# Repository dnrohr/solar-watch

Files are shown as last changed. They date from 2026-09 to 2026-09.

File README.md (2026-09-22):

# Solar Watch

The repository contains the digitally validated P0 solar reference, the P1
fixed-latitude cam bench, and the Rev-A CNC-ready P2 fixed-latitude display for
42.1 degrees north. P2 is ready for quotation and physical coupon/module tests;
its fabrication-dependent accuracy is not yet claimed.

## P2 release package

- `output/pdf/solar_watch_p2_design_dossier_revA.pdf` — design basis,
  validation evidence, interfaces, verification matrix, and risks;
- `output/pdf/solar_watch_p2_custom_part_drawings_revA.pdf` — 28 controlled
  custom-part sheets;
- `output/pdf/solar_watch_p2_procurement_test_revA.pdf` — BOM, RFQ, assembly,
  calibration, and acceptance procedure;
- `cnc/p2/` — STEP, DXF, STL preview, cam profile CSV, assembly STEP, manifest,
  and SHA-256 list;
- `src/solar_watch/p2.py` and `src/solar_watch/p2_cad.py` — kinematic and CAD
  sources.

Run `scripts/bootstrap.ps1`, then `scripts/regenerate.ps1` and
`scripts/verify.ps1`. PDF generation additionally uses the free ReportLab
runtime documented in `docs/software-tooling.md`.

Solar Watch is a large-format mechanical astronomical display. Its
three solar indications show:

- sunrise time;
- sunset time; and
- sunrise and sunset azimuth on one 360-degree dial.

The target demonstrator occupies no more than a 36 by 24 inch frontal area and
accepts latitude and date as astronomical inputs. A conventional clock movement
may later provide local time independently.

The P0 numerical reference, P1 cam package, and P2 CNC design are complete in
software for 42.1 degrees north. Decision 0006 records the user's choice to
bypass P1 fabrication. The next action is to quote and machine the P2 coupons,
then release production parts only after those coupons pass.

## Start here

- [Project brief](docs/project-brief.md)
- [Requirements](docs/requirements.md)
- [Conventions](docs/conventions.md)
- [Provisional architecture](docs/architecture.md)
- [Risk register](docs/risk-register.md)
- [Software and tooling](docs/software-tooling.md)
- [Open decisions](docs/open-decisions.md)
- [P0 numerical validation](docs/p0-validation.md)
- [P1 cam package](docs/p1-cam-package.md)
- [P1 bill of materials](docs/bom.md)
- [Print and test procedure](docs/print-test-procedure.md)
- [P2 design basis](docs/p2-design-basis.md)
- [P2 interface control](docs/p2-interface-control.md)
- [P2 mechanical analysis](docs/p2-mechanical-analysis.md)
- [P2 bill of materials](docs/p2-bom.md)
- [P2 RFQ](docs/p2-rfq.md)
- [P2 vendor shortlist and budget](docs/p2-vendor-budget.md)
- [P2 manufacture and test](docs/p2-manufacturing-test.md)

## Reproduce and verify P0/P1/P2

The toolchain is free and project-local. From PowerShell with Python 3.12:

```powershell
.\scripts\bootstrap.ps1
.\scripts\verify.ps1
```

Generated reference data lives in `data/`, diagnostic plots in
`artifacts/plots/`, print-ready P1 files in `printables/p1/`, and CNC P2 files in
`cnc/p2/`.
Normal verification is offline; refreshing the independent JPL DE421 fixture is
an explicit separate command documented in the P0 report.

Documents marked **Provisional** contain assumptions that may change after the
first design review.

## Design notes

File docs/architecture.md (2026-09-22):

# Provisional System Architecture

Status: P2 Rev A
Date: 2026-09-21

## Functional decomposition

```text
Calendar input ─┬─> solar-geometry function ─> sunrise azimuth ─> sunrise hand
                │                                      └───────> mirrored sunset hand
Latitude input ─┘

Calendar input ─┬─> daylight function ─> daylight-duration displacement ─┐
Latitude input ─┘                                                         │
                                                                          v
Manual sunrise-time input ─────────────────────────────────────────> time summer
                                                                          │
                                                                          v
                                                                  sunset-time hand
```

The local-time clock, if installed, is an independent module.

## Computational degrees of freedom

The ideal-horizon mechanism needs to generate only two independent astronomical
outputs:

1. sunrise azimuth; and
2. daylight duration.

Sunset azimuth is obtained by reflection around the north-south meridian.
Sunset time is obtained by adding daylight duration to an established sunrise
time. This reduction is central to keeping the printed mechanism achievable.

## Proposed final modules

### A. Input module

- Manually positioned annual date shaft
- Latitude carriage covering -60 through +60 degrees
- Manually positioned sunrise-time shaft
- Setting scales and positive locks

### B. Astronomical cam module

- One two-input cam surface for daylight duration
- One two-input cam surface for sunrise azimuth
- Shared latitude carriage
- Spring-preloaded roller followers
- Replaceable and individually adjustable output couplings

The leading candidate is a pair of cylindrical surface cams. Circumferential
position represents date, axial follower position represents latitude, and cam
radius or groove displacement represents the result.

### C. Time module

- Converts daylight-cam displacement into angular time displacement
- Adds that displacement to the manually established sunrise indication
- Drives the sunset-time hand
- Provides independent zero and span calibration

The first implementation may use a linear cable or belt summer. A printed bevel
or planetary differential should be introduced only after required ranges and
torques have been measured.

### D. Azimuth module

- Converts azimuth-cam displacement into sunrise-hand rotation
- Produces equal and opposite sunset-hand movement
- Provides independent zero and span calibration

The sunrise and sunset hands may be coaxial if a sufficiently stiff concentric
shaft can be fabricated. Separate nearby axes are an acceptable prototype
fallback.

### E. Display and frame

- Sunrise-time dial
- Sunset-time dial
- Combined 360-degree azimuth dial
- Date and latitude setting scales
- Structural backplane
- Protective guards over pinch points and exposed cams
- Optional independent local-time clock

## Prototype sequence

### P0: Numerical model — digitally complete

No mechanism. Produces verified tables and error sweeps. NREL SPA is validated
for every 2025 day at 42.1 degrees north against Skyfield/JPL DE421.

### P1: Fixed-latitude cam bench — print package complete, physical test pending

- Fixed at 42.1 degrees north
- Manually rotated date input
- One-dimensional daylight and azimuth cams
- Direct measurement scales instead of finished dials

Purpose: measure printed cam accuracy, follower behavior, backlash, and useful
mechanical scale.

### P2: Fixed-latitude display — digitally complete, physical build pending

- Three display dials
- Mirrored azimuth output
- Manual sunrise setting
- Time-summing mechanism

Purpose: validate the complete information architecture and dial readability.

P2 detailed design freezes a 609 x 900 x 200 mm portrait assembly. Two 10 mm
POM-C radial cams share a keyed 12 mm manual date shaft. The daylight output and
manual sunrise setting enter an opposed-rack translating-pinion summer; its
carrier position is one half the linear sum and a 7.5 mm output pitch radius
restores the full angular sum. The sunrise azimuth output drives an 80-tooth
pinion and a preloaded 1:1 miter reverser drives the concentric sunset hand.
Independent zero, span, and phase adjustments are accessible behind the guard.

See `p2-design-basis.md`, `p2-interface-control.md`, and Decision 0004.

### P3: Variable-latitude cam bench

- Two surface cams
- Shared latitude carriage
- Temporary direct scales

Purpose: isolate and validate the main two-variable mechanism.

### P4: Integrated demonstrator

- Variable latitude
- Three solar dials
- Finished controls and calibration features
- Optional independent local-time movement

## Interfaces requiring measurement before detailed design

| Interface | Provisional representation | Must be established by |
|---|---|---|
| Date input | 360 degrees per selected reference year | P0/P1 design |
| Latitude input | Linear carriage position | P3 design |
| Daylight output | 0.1308997 mm/min, 16 mm roller | P2 CAD; physical acceptance pending |
| Azimuth output | 0.6981317 mm/degree, 16 mm roller | P2 CAD; physical acceptance pending |
| Time indication | 240 mm 12-hour dial, 5-minute divisions | P2 DXF |
| Azimuth indication | 360 mm combined dial, 5-degree divisions | P2 DXF |

## Design rules

- Every precision output receives zero adjustment.
- Span adjustment is preferred where cam scale or linkage ratio may vary.
- Followers remain preloaded through their complete operating domain.
- Printed holes do not serve directly as precision bearings.
- Modules can be tested separately before installation in the frame.
- Cam geometry is generated from source data and is never edited manually as an
  unexplained mesh.
- Generated files record the model version and input parameters used to create
  them.

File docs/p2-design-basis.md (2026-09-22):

# P2 Fixed-Latitude Design Basis

Status: Released for quotation, Rev A
Latitude: 42.1 degrees north
Units: millimetres unless noted

## Scope and evidence boundary

P2 is a full-size, manually set, fixed-latitude astronomical display. One date
input drives the P0-validated daylight-duration and sunrise-azimuth cams. The
operator separately sets sunrise time. The mechanism displays sunrise time,
mechanically calculates sunset time, and displays mirrored sunrise and sunset
azimuths. The package intentionally stops before variable latitude, automatic
civil-time correction, decorative dial artwork, or the P3/P4 mechanisms.

The solar model, cam profiles, linkage equations, nominal clearances, and CAD
envelopes are digitally verified. Cutting accuracy, bearing fits, friction,
preload, backlash, stiffness, and achieved indication error remain physical
acceptance items. Decision 0006 records the deliberate P1 test bypass.

## Display and frame

The controlled external envelope is 609 wide by 900 high by 200 deep. A
20-series metric T-slot perimeter supports three removable 6 mm 6061-T6 module
plates and a 4.5 mm clear polycarbonate guard. The front layout uses these
dial centers from the lower-left corner:

| Display | Center X | Center Y | Diameter | Minor division |
|---|---:|---:|---:|---:|
| Sunrise azimuth / sunset azimuth | 304.5 | 665 | 360 | 5 degrees |
| Sunrise time | 165 | 285 | 240 | 5 minutes |
| Sunset time | 444 | 285 | 240 | 5 minutes |
| Date setting | 304.5 | 82 | 110 | monthly reference |

The five-minute time spacing is 5.236 mm on the dial rim. Five azimuth degrees
occupies 15.708 mm. The functional scales are engraved or UV printed on 2.5 mm
anodized aluminum; decorative artwork remains outside P2.

## Cam stack and date datum

Both cams retain the P1 translating 16 mm roller geometry and validated scales:

| Cam | Datum | Follower scale | Pitch radius | Surface radius range |
|---|---:|---:|---:|---:|
| Daylight duration | 545 min | 0.1308997 mm/min | 48 mm nominal | generated manifest |
| Sunrise azimuth | 55 degrees | 0.6981317 mm/degree | 48 mm nominal | generated manifest |

Each 10 mm POM-C cam pilots on a 32 H7/h6 metal hub register, clamps with three
M5 screws on a 40 mm bolt circle, and has a 4 mm indexing dowel at radius 20,
60 degrees counter-clockwise from the January 1 profile ray. The pair shares a
12 mm keyed date shaft. A split-clamp shaft collar gives
continuous date phase adjustment of at least plus/minus 3 degrees after the
dowel-defined nominal phase is established. Rotate the date control clockwise
to advance the calendar while the followers remain on the positive-X datum ray.

The visible date control at (304.5, 82) drives the common cam shaft at
(224.5, 375) through two 30-tooth HTD-5M pulleys and one 760 mm, 15 mm-wide
belt. Equal tooth counts preserve 1:1 date phase. A smooth-back idler on a slot
sets 10 to 20 N static belt tension and provides assembly tolerance. The date
phase collar is downstream of the belt so belt indexing does not alter the cam
datum. The belt is always approached clockwise during setting; bidirectional
phase hysteresis is measured separately.

Cam faces are finish-machined together to 10.00 plus/minus 0.03 thickness.
Profile tolerance is 0.05 relative to datum A (hub pilot); face parallelism and
shaft-axis perpendicularity are 0.05. The follower surface is Ra 1.6 micrometre
or better, with edges broken 0.2 maximum. Do not polish across the datum pilot.

## Daylight-to-sunset mechanism

The sunrise knob drives a 15 mm pitch-radius pinion and the sunrise hand. Its
rack travel is 94.248 mm for one 12-hour revolution. The P2 daylight cam directly
encodes the required rack scale, so the daylight calibration lever is nominally
1:1; its annual rack range is approximately 48.31 mm.

Two opposed module-1 input racks constrain a freely rotating module-1, 15-tooth
planet pinion carrier to their arithmetic mean. Carrier translation therefore
equals one half of the summed rack positions. A third rack attached to the
carrier drives a fixed-axis module-1, 15-tooth output pinion; its 7.5 mm pitch
radius converts carrier translation back to the full angular sum. The sunset
phase clamp removes the constant 545-minute cam datum. Nominal
kinematics are:

```text
x_sunrise = 15 rad(0.5 degrees/minute times sunrise_minutes)
x_daylight = 0.1308997 times (daylight_minutes - 545)
x_carrier = (x_sunrise + x_daylight) / 2
sunset_angle = x_carrier / 7.5 + phase
```

The racks are spring-biased against opposite tooth flanks by a 1 to 2 N
extension spring. Rack guides use dry-running polymer bushings; oil is not
permitted near POM cams. Carrier end stops provide 3 mm reserve beyond the
calculated motion. The sunset zero collar provides plus/minus 15 degrees and
the daylight lever slot provides plus/minus 2 percent span adjustment.

## Azimuth mechanism

The P2 azimuth cam directly encodes 0.6981317 mm/degree. Its follower drives a
rack through a nominal 1:1 adjustable calibration lever. The rack turns a
module-1 pinion with 40 mm pitch radius (80 teeth),
so one true azimuth degree produces one output degree. A preloaded 1:1 miter
gear pair reverses the sunset output around the north-south meridian. The
sunrise hand mounts on an 8 mm inner shaft and the sunset hand on a 14 mm OD by
8.1 mm ID outer tube. Two opposed spring washers remove axial clearance.

The sunrise zero collar allows plus/minus 5 degrees; the lever slot allows
plus/minus 2 percent span. The sunset hand has an independent zero clamp so the
two hands can be made symmetric at the equinox without disturbing the cam.

Both calibration levers use exact tangent-intersection geometry. A
center-pivoted 180 mm lever has separate radial slots on each side. Input and
output crosshead pins move on parallel guides at nominal offsets of minus and
plus 75 mm, so their displacement ratio equals the ratio of guide offsets.
Shifting the output guide from 73.5 to 76.5 mm provides 0.98:1 through 1.02:1
span without trigonometric scale error. Spring-biased slot rollers remove play;
the calibrated guide is clamped by two bolts and jam nuts.

## Followers, preload, and bearings

Both cams use sealed 16 mm OD by 5 mm bore track rollers, 7 mm nominal width,
on shoulder screws. Each follower has 1 to 3 N positive preload throughout its
travel and a mechanical retainer that prevents a disengaged roller from
contacting the adjacent cam. All rotating display shafts run in replaceable
flanged ball bearings or oil-impregnated bronze bushings located by machined
module plates. Printed holes are not precision bearings.

## Mechanical analysis and error allocation

The automated full-year sweep, pressure-angle loads, input torque, shaft/frame
deflection, travel, interference clearances, backlash allocations, readability,
and root-sum-square error budget are controlled by
`p2-mechanical-analysis.md`. Estimated RSS is 0.768 minute and 0.557 degree
against one-minute and one-degree targets. These are design estimates; physical
module and integrated sweeps are required before the targets can be claimed.

## Adjustment order

1. Inspect the hub pilot and shaft runout coupons.
2. Set date phase at January 1 with both cam dowels installed.
3. Set daylight and azimuth follower preload to 1 to 3 N.
4. Set daylight lever span using the minimum and maximum reference dates.
5. Set sunset zero at the 545-minute daylight datum.
6. Set azimuth lever span at the two solstice reference points.
7. Set sunrise azimuth zero, then set the reversed sunset hand for symmetry.
8. Lock all jam nuts, witness-mark clamps, and repeat the full sweep.

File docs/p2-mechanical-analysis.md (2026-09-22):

# P2 Mechanical Analysis and Error Budget

Status: Digitally verified Rev A; fabrication evidence pending

## Full-year sweep

The committed analysis evaluates 365 dates at 48 sunrise settings in 15-minute
steps: 17,520 states. The mathematical rack differential reproduces
`(sunrise + daylight) mod 12 hours` with a maximum numerical kinematic error of
2.3e-13 degree. The P0 mirror approximation differs from independently computed
sunset azimuth by at most 0.277 degree. The full table is
`data/p2_full_year_motion_sweep_42p1N_2025.csv`.

| Travel | Minimum | Maximum | Allocated usable travel |
|---|---:|---:|---:|
| Sunrise input rack | 0.000 mm | 92.284 mm at 11:45 | 100 mm |
| Daylight input rack | 0.164 mm | 48.471 mm | 55 mm |
| Carrier output rack | 0.082 mm | 70.378 mm | 78 mm |
| Azimuth rack | 1.176 mm | 46.451 mm | 55 mm |

Each guide receives at least 3 mm end reserve beyond the analyzed range. The
sunrise rack additionally accommodates the untested 11:45-to-12:00 setting
margin up to the 94.248 mm theoretical full turn.

## Cam contact, force, and input torque

At the maximum specified 3 N follower preload, the daylight cam has 18.52-degree
maximum pressure angle, 13.23 mm minimum pitch-curve curvature radius, 1.01 N
maximum tangential follower force, and 65.14 N mm maximum ideal cam torque. The
azimuth cam values are 17.58 degrees, 33.93 mm, 0.96 N, and 64.76 N mm. Both
curvature radii exceed the 8 mm roller radius.

The two worst cam torques plus 40 N mm bearing/collar allowance total about
170 N mm. The date input is designed and acceptance-tested at 250 N mm; a 50 mm
radius handwheel therefore requires no more than 5 N hand force and provides a
1.47 torque factor over the calculated nominal worst case. The sunrise input
design torque is 75 N mm including 3 N working and 2 N preload forces, or 1.88 N
at a 40 mm knob radius. Measure actual torque before installing the dials.

## Deflection

An 8 mm stainless shaft with a 25 mm cantilever under 3 N deflects 0.00041 mm
by Euler-Bernoulli beam theory. A 569 mm 20x40 extrusion span loaded at midspan
with 10 N on its published weak-axis inertia deflects 0.046 mm. These estimates
are below the 0.01 mm shaft and 0.10 mm frame allocations. Joint slip, plate
flatness, and mounting compliance remain physical inspection items.

## Clearance and interference

Automated planar and depth checks establish:

| Check | Result | Requirement |
|---|---:|---:|
| Minimum dial-edge gap | 39.0 mm | at least 20 mm |
| Guard inner face to hand stack | 8.0 mm | at least 8 mm |
| Depth margin to 200 mm envelope | 21.5 mm | at least 20 mm |
| Minimum cam profile-to-pilot radial wall | 24.16 mm | at least 10 mm |
| Time / azimuth hand tip margin | 15 / 15 mm | at least 10 mm |

The assembly STEP and A01-A03 drawings additionally define module zones. The
digital check cannot prove cable, spring, washer, or fastener-head clearance;
the build procedure requires an unguarded slow sweep followed by an 8 mm guard
clearance gauge check.

## Backlash and hysteresis allocation

Commercial gear catalog backlash is not the achieved system lost motion. The
design uses opposed flank springs on all three time racks and axial spring
preload on the miter pair. The error budget assumes residual time-rack lost
motion of 0.020 mm (0.306 minute at the 7.5 mm output radius), azimuth spur lost
motion of 0.020 mm (0.029 degree), and miter lost motion of 0.030 mm at a 10 mm
pitch radius (0.172 degree). These are acceptance limits, not vendor default
claims. Directional tests must measure them after assembly.

## Combined error budget

Independent terms are combined by root-sum-square for planning. This is not a
guarantee because some fabrication errors can be correlated.

| Contribution | Time, min | Azimuth, deg |
|---|---:|---:|
| P0 numerical reference | 0.0022 | 0.00013 |
| 0.05 mm cam profile | 0.382 | 0.072 |
| 0.025 mm hub runout | 0.191 | 0.036 |
| 0.020 mm follower/linkage | 0.153 | 0.029 |
| Preloaded spur/rack residual | 0.306 | 0.029 |
| Preloaded miter residual | not applicable | 0.172 |
| Calibration residual | 0.200 | 0.150 |
| Reading/parallax | 0.500 | 0.500 |
| **Estimated RSS** | **0.768** | **0.557** |
| **Acceptance target** | **1.000** | **1.000** |

Functional time ticks are five minutes apart, 5.236 mm at the rim; a one-minute
interpolation is approximately 1.047 mm. Five azimuth degrees span 15.708 mm;
one degree spans 3.142 mm. Hands require a tip width at most 0.6 mm and a dial
gap of 1.5 to 3 mm to keep the stated reading allocation credible.

## Reproduction

Run `python -m solar_watch.cli analyze-p2 --root .`. The command regenerates the
full sweep, JSON summary, and mechanical verification plot. Automated tests
assert kinematic exactness, travel coverage, clearance, deflection, RSS targets,
and that physical validation remains marked pending.

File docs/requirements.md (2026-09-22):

# Requirements

Status: Draft v0.2
Date: 2026-09-21

The words **shall**, **should**, and **may** distinguish required behavior,
preferred behavior, and optional behavior. Requirements labeled `TBD` are not
approved until their associated open decision is resolved.

## Functional requirements

| ID | Requirement | Verification |
|---|---|---|
| FUN-001 | The system shall indicate sunrise time. | Inspection and reference comparison |
| FUN-002 | The system shall indicate sunset time. | Inspection and reference comparison |
| FUN-003 | The system shall indicate sunrise azimuth on a 360-degree compass scale. | Inspection and reference comparison |
| FUN-004 | The system shall indicate sunset azimuth on the same compass scale. | Inspection and reference comparison |
| FUN-005 | The final demonstrator shall accept latitude from 60 degrees south through 60 degrees north. | Full-range test |
| FUN-006 | The system shall accept a seasonal or calendar-date input. | Inspection and annual sweep |
| FUN-007 | The sunset-azimuth indication may be mechanically mirrored from the sunrise-azimuth indication. | Analysis and comparison |
| FUN-008 | The initial system shall permit manual positioning of the date input. | Demonstration |
| FUN-009 | The first cam prototype shall use one fixed latitude. | Design inspection |
| FUN-010 | An independent conventional movement may indicate current local time. | Optional inspection |

## Astronomical requirements

| ID | Requirement | Verification |
|---|---|---|
| AST-001 | Reference sunrise and sunset shall use an apparent solar-center altitude of -0.833 degrees unless subsequently revised. | Model inspection |
| AST-002 | Azimuth shall be measured clockwise from true north. | Model and dial inspection |
| AST-003 | Latitude shall be positive north and negative south. | Model tests |
| AST-004 | The reference model shall distinguish calendar date from solar declination. | Model inspection |
| AST-005 | The model shall report when an input is outside the supported domain rather than silently extrapolating. | Automated boundary test |
| AST-006 | Ideal-horizon sunrise and sunset azimuths may be treated as mirror images if the introduced error remains below the azimuth error allocation. | Numerical sweep |

## Accuracy requirements

| ID | Requirement | Verification |
|---|---|---|
| ACC-001 | The numerical reference model shall differ from the selected validation ephemeris by no more than 0.1 minute in event time within the supported domain. | Automated comparison |
| ACC-002 | The numerical reference model shall differ from the selected validation ephemeris by no more than 0.1 degree in azimuth within the supported domain. | Automated comparison |
| ACC-003 | The integrated mechanism should indicate event time within one minute of the reference model. | Calibrated grid test |
| ACC-004 | The integrated mechanism shall indicate event azimuth within one degree of the reference model. | Calibrated grid test |
| ACC-005 | Repeat measurements made after approaching a setting from the prescribed direction should agree within one minute and one degree. | Repeatability test |
| ACC-006 | Backlash and hysteresis shall be measured separately from absolute calibration error. | Bidirectional test |
| ACC-007 | The time dials should provide markings at intervals of no more than five minutes. | Inspection |
| ACC-008 | The azimuth dial should provide markings at intervals of no more than five degrees. | Inspection |

`ACC-003` is initially a design target rather than a release claim. It will be
reclassified after the first physical cam tests establish the achievable error
budget for printed parts.

## Mechanical requirements

| ID | Requirement | Verification |
|---|---|---|
| MEC-001 | The integrated display shall fit within a 36 by 24 inch frontal envelope. | Measurement |
| MEC-002 | The P2 mechanism shall not exceed 200 mm overall depth. P3 shall revisit this limit. | CAD envelope and measurement |
| MEC-003 | Major printed assemblies shall be segmentable for the available printer build volume. | CAD inspection |
| MEC-004 | Cam followers shall be positively preloaded by a spring, gravity, or equivalent method. | Inspection |
| MEC-005 | Output indications shall provide an accessible zero or calibration adjustment. | Inspection |
| MEC-006 | Rotating load-bearing elements should use replaceable metal shafts and bearings or bushings. | BOM and inspection |
| MEC-007 | Failure or removal of the optional local-time clock shall not disable the solar computation. | Demonstration |
| MEC-008 | User-adjustable mechanisms shall include end stops where motion outside the supported domain could cause damage. | Inspection and boundary test |
| MEC-009 | The date and latitude controls shall display their current settings. | Inspection |

## Fabrication requirements

| ID | Requirement | Verification |
|---|---|---|
| FAB-001 | P1 prototype parts shall remain manufacturable using consumer 3D printing. P2 precision computational parts may use CNC manufacture under Decision 0005. | File and drawing inspection |
| FAB-002 | Purchased components should be commonly available metric hardware where practical. | BOM review |
| FAB-003 | Parts that determine calibration shall include identifying marks and revision identifiers. | Inspection |
| FAB-004 | Printed cam surfaces shall permit finishing without changing their datum references. | Process trial |
| FAB-005 | The design shall not require printed shafts running directly in printed structural holes for precision outputs. | CAD inspection |

## Service and documentation requirements

| ID | Requirement | Verification |
|---|---|---|
| DOC-001 | Each physical build shall have a unique identifier. | Build record inspection |
| DOC-002 | Each physical build shall record material, printer, slicer settings, and part revisions. | Build record inspection |
| DOC-003 | Reference data and printable cam geometry shall be reproducible from version-controlled source files. | Clean regeneration test |
| DOC-004 | Assembly and calibration shall be possible without modifying source CAD. | Procedure trial |
| DOC-005 | Major design decisions shall record context, alternatives, and rationale. | Decision-log review |

## P2 fixed-latitude requirements

| ID | Requirement | Verification |
|---|---|---|
| P2-001 | One manual date input shall phase both fixed-latitude cams through one 365-day cycle. | Annual motion sweep |
| P2-002 | The sunrise-time input shall directly establish the sunrise indication without altering astronomical cam outputs. | Kinematic analysis and test |
| P2-003 | The sunset indication shall equal sunrise time plus daylight duration modulo 12 hours. | Full-year and input-grid sweep |
| P2-004 | Sunrise and sunset azimuth hands shall be concentric and equal/opposite about the north-south meridian. | Kinematic sweep |
| P2-005 | Daylight, time-summing, and azimuth modules shall be independently inspectable and calibratable. | Drawing and procedure inspection |
| P2-006 | The functional azimuth dial shall be at least 360 mm diameter and the time dials at least 240 mm diameter. | Drawing inspection |
| P2-007 | P2 shall provide independent zero, span, and date-phase adjustments without modifying source CAD. | Adjustment-range analysis |
| P2-008 | Custom CNC parts shall define datums, material, finish, critical tolerances, and inspection requirements on drawings. | Drawing review |
| P2-009 | The design shall distinguish digitally verified performance from fabrication-dependent acceptance evidence. | Verification matrix review |
| P2-010 | No single module shall require removal of another calibrated module for routine adjustment or inspection. | Assembly/service review |

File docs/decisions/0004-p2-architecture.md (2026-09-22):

# Decision 0004: P2 Fixed-Latitude Architecture

Status: Accepted for detailed design

Date: 2026-09-21

## Context

P2 must convert the two validated fixed-latitude cam outputs into three readable
displays while keeping backlash, calibration, and service interfaces explicit.
The user has chosen to proceed directly to P2 and prioritize accurate CNC parts.

## Decision

P2 will use a portrait `609 x 900 mm` frontal envelope and no more than `200 mm`
overall depth. The functional layout is a `360 mm` azimuth dial above two
`240 mm` time dials. The mechanism remains visible behind a removable clear
guard.

A shared manual date shaft carries both fixed-latitude cams. The shaft is
supported in replaceable bearings; each CNC acetal cam bolts to a keyed metal
hub so profile parts can be inspected, replaced, or re-phased independently.

The time module uses a linear rack differential:

- a `15 mm` pitch-radius sunrise input converts sunrise-shaft rotation to rack
  travel;
- the P2 daylight cam directly encodes the required `0.1308997 mm/min` rack
  scale and drives the opposed input rack through a nominal `1:1` calibration
  lever;
- the differential pinion carrier moves by half the sum of the rack inputs; and
- a third rack fixed to the carrier drives a `7.5 mm` pitch-radius output pinion
  and restores the full angular sum on the sunset shaft.

The P2 azimuth cam directly encodes `0.6981317 mm/degree` and drives a nominal
`40 mm` pitch-radius pinion through a `1:1` calibration lever. A preloaded 1:1 bevel reverser couples the
sunrise inner shaft to the concentric sunset tube, producing equal and opposite
hand motion.

The structural system uses a metric T-slot perimeter frame with local CNC 6061
module plates. Precision is established locally by dowels, bearings, and module
plates rather than by a single full-size machined backplane.

## Alternatives considered

- A bevel or planetary rotary differential for time summation was more compact
  but introduced custom gear geometry, less transparent ratios, and additional
  backlash.
- Moving the entire cam module with the sunrise setting produced a direct sum
  but imposed unnecessary mass and date-shaft coupling.
- Separate azimuth axes simplified fabrication but failed to exercise the
  combined compass display intended for P2.
- A full `609 x 900 mm` aluminum backplate was stiff but expensive to machine
  and ship; local datum plates provide the required precision more economically.

## Consequences

- The time sum is visible, measurable, and independently testable in linear
  coordinates before dial installation.
- Zero, span, and phase remain separate adjustments.
- Rack preload and bevel preload are required to control reversal error.
- Functional dial scales are in scope, but decorative artwork remains deferred.
- The P2 architecture is fixed-latitude and does not pre-design P3 surfaces.

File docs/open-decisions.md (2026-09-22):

# Open Decisions

Status: Draft v0.1  
Date: 2026-09-21

This is the decision queue for items that materially affect the design. Each
entry includes a recommended default so work can continue while a response is
pending.

## Resolved decisions

- D-001: The first fixed-latitude prototype will use 42.1 degrees north. See
  [decision record 0001](decisions/0001-p1-latitude.md).
- D-003 (P1 portion): use a manual continuous 365-day wheel, advancing clockwise
  by 360/365 degrees per day. Automatic drive and leap-year behavior remain open.
- P0 algorithm and calendar: see [decision record 0002](decisions/0002-p0-reference.md).
- P1 cam/follower geometry: see [decision record 0003](decisions/0003-p1-cam-geometry.md).
- P2 architecture and layout: see [decision record 0004](decisions/0004-p2-architecture.md).
- P2 CNC materials and datums: see [decision record 0005](decisions/0005-p2-cnc-strategy.md).
- P1 physical-test bypass: see [decision record 0006](decisions/0006-p1-test-bypass.md).

## D-002: Time-reference behavior (resolved for P2)

**P2 decision:** manually set sunrise time; calculate sunset by adding
daylight duration

Alternatives considered:

- manually set sunrise and calculate sunset;
- manually set solar noon and calculate both event times symmetrically;
- calculate apparent-solar times around 12:00;
- calculate full civil times using longitude, equation of time, time zone, and
  daylight-saving corrections; or
- manually set both event-time hands, leaving only azimuth calculated.

The recommended option best isolates the latitude/date computation while still
demonstrating a meaningful mechanical time calculation.

## D-003: Date input (automatic-drive remainder)

**Needed before:** an annual automatic drive after P1

**P1 decision:** manual continuous 365-day date input

A continuous wheel allows sub-day testing and avoids the torque and calendar
complexity of an automatic annual drive. An automatic drive can be added after
the required cam torque is measured.

## D-004: Display orientation (resolved for P2)

**P2 decision:** portrait `609 x 900 mm` panel, azimuth dial above two time
dials. Functional scales are designed in P2; decorative artwork remains later.

Landscape and exposed-mechanism layouts remain possible. The mechanism should be
designed as independent modules so the front-panel arrangement does not alter
the mathematics.

## D-005: Maximum depth (resolved for P2)

**P2 decision:** `200 mm` overall target and limit. P3 packaging will reopen the
decision because its surface cams differ.

Allowing generous initial depth reduces the risk of compressing the mechanism
before its necessary cam travel and follower geometry have been measured.

## D-006: Printer constraints (superseded for P2 precision parts)

**P2 decision:** computational and precision transmission parts are specified
for CNC manufacture. P1 print files remain available as test artifacts.

Revision A was generated on the recommended assumption while numerical and
mechanical work proceeded. The one-piece cams need roughly a 135 mm square
footprint before brim. The actual printer, usable build volume, nozzle, material,
and layer height must be recorded before slicing; a smaller bed or different
nozzle may require revision B.

## D-007: Visible mechanism (resolved for P2)

**P2 decision:** expose cams and transmissions behind a removable clear
polycarbonate guard.

The mechanism is central to the object's appeal and makes calibration and fault
finding easier. A concealed mechanism could make the finished object resemble a
more conventional clock but would reduce its explanatory value.

## D-008: Hemisphere labeling

**Needed before:** variable-latitude input design  
**Recommended default:** one signed latitude scale from 60 S through 60 N

This keeps the mathematical convention visible. A separate hemisphere selector
could make the scale larger but introduces another setting that can be wrong.

## Decision-record format

Once resolved, significant decisions move to `docs/decisions/` using a short
record containing:

- context;
- selected approach;
- alternatives considered;
- consequences; and
- date of decision.

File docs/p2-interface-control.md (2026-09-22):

# P2 Interface Control Document

Status: Released for quotation, Rev A
All dimensions are millimetres. CAD is master for profile geometry; this file
is master for functional interfaces and acceptance.

## Coordinate system

Front view uses X right, Y up, and Z toward the viewer. The overall origin is
the lower-left corner of the 609 by 900 envelope. Cam-fixed profile angle zero
is the positive-X January 1 ray. The 4 mm indexing dowel is at radius 20 and 60
degrees counter-clockwise from that ray to avoid the three M5 clamp screws.
Positive cam profile angles are counter-clockwise; the installed date knob
advances clockwise.

## Controlled interfaces

| ID | Interface | Nominal | Fit / tolerance | Verification |
|---|---|---:|---|---|
| I-01 | Cam-to-hub pilot | 32 diameter | H7 cam / h6 hub | bore gauge, micrometer |
| I-02 | Cam clamp circle | 3 x M5 on 40 PCD | true position 0.10 to I-01 | CMM or pins |
| I-03 | January 1 datum | 4 reamed at radius 20, 60 deg CCW from profile zero | H7, position 0.05 to I-01 | CMM or height gauge |
| I-04 | Hub-to-date shaft | 12 diameter keyed | H7 bore, commercial key | plug gauge |
| I-05 | Cam face stack | 10 each | plus/minus 0.03; parallel 0.05 | micrometer |
| I-06 | Roller follower | 16 OD x 5 bore | commercial sealed bearing | certificate / measure |
| I-07 | Time rack/pinion | module 1, 20 degree PA | quality 8 or better | supplier certificate |
| I-08 | Sunrise pinion | 30 tooth | 15 pitch radius | roll test |
| I-09 | Differential/output pinions | 15 tooth | 7.5 pitch radius | roll test |
| I-10 | Azimuth pinion | 80 tooth | 40 pitch radius | roll test |
| I-11 | Azimuth coaxial shafts | 8 shaft, 14/8.1 tube | 0.05 diametral running clearance | gauges |
| I-12 | Module plate mounting | M6 clearance | 6.6 diameter | plug gauge |
| I-13 | Front guard | 585 x 875 x 4.5 | plus/minus 0.5 outline | tape / caliper |
| I-14 | Overall envelope | 609 x 900 x 200 maximum | must not exceed | assembled measurement |
| I-15 | Date belt transmission | HTD-5M, 30T:30T, 760 length, 15 width | 1:1; 10-20 N static tension | tension gauge / phase sweep |

## Datum scheme for custom parts

- Cams: datum A is the 32 mm pilot axis; B is the rear face; C is the January 1
  dowel hole. The generated profile is basic relative to A and C.
- Hubs: A is the 12 mm shaft bore axis; B is the rear flange face; C is the hub
  dowel hole. Pilot runout is 0.025 total indicated relative to A.
- Module plates: A is the rear mounting face, B the lower long edge, and C the
  left short edge. Bearing and shaft locations are basic from B/C.
- Levers: A is the pivot bore; B is one broad face; C is the roller-slot center
  plane. Pivot-to-slot setting is adjustable and locked by two jam nuts.
- Shafts: A is the bearing journal axis; B is the front shoulder. Display hub
  runout is 0.025 total indicated relative to A.

## General drawing notes

1. ISO 2768-mK applies unless specifically toleranced.
2. Deburr and break sharp edges 0.2 to 0.5; never roll or hand-blend cam profiles.
3. Aluminum is 6061-T6, clear anodized 8 to 12 micrometres after machining;
   mask bearing fits and electrical bonding points.
4. Cams are stress-relieved, machinable POM-C/acetal, black or natural. Machine
   both faces in one setup after roughing and allow 24 hours before finishing.
5. Shafts are 303 stainless, ground journals Ra 0.8 micrometre or better.
6. Polycarbonate guard edges are polished only after all holes are complete.
7. Supplier shall return dimensional inspection results for I-01 through I-05
   and shaft runout. No material substitution without written approval.
8. STEP controls 3D form. DXF controls flat profiles. PDF drawing notes control
   tolerances, finishes, and inspection.

## Assembly stack along Z

The frame rear plane is Z0. Module plates mount at Z35. The cam stack occupies
Z48 through Z82 including hubs, spacers, and followers. Rack modules occupy
Z88 through Z125. The date belt occupies Z130 through Z145. Dial faces lie at
Z154 through Z156.5, hands at Z160 to Z166, and the guard
inner face at Z174. The guard outer face at Z178.5 leaves at least 21.5 mm to
the 200 mm maximum envelope for fasteners and stand-off variation.

## Module placement in front coordinates

| Module / axis | X | Y | Interface |
|---|---:|---:|---|
| Cam module plate center | 304.5 | 450 | P2-104, 360 x 340 |
| Common cam/date shaft | 224.5 | 375 | local (-80,-75) on P2-104 |
| Date control shaft | 304.5 | 82 | 1:1 HTD link to cam shaft |
| Time module plate center | 304.5 | 285 | P2-108, 320 x 180 |
| Sunrise shaft | 165 | 285 | local X -139.5 on P2-108 |
| Sunset shaft | 444 | 285 | local X +139.5 on P2-108 |
| Azimuth module / coaxial shaft | 304.5 | 665 | P2-109 center |

The cam plate overlaps dial projections only in X/Y; its Z35-to-Z82 mechanism
zone is behind the Z154 dial plane. Belt, spring, and fastener-head clearance is
confirmed by the mandatory unguarded physical sweep.

## Adjustment provisions

| Adjustment | Range | Locking method | Witness mark |
|---|---:|---|---|
| Date phase | plus/minus 3 degrees | split hub collar | shaft/hub line |
| Daylight span | plus/minus 2 percent | slotted lever, two jam nuts | lever scale |
| Sunset zero | plus/minus 15 degrees | split output collar | collar/shaft line |
| Azimuth span | plus/minus 2 percent | slotted lever, two jam nuts | lever scale |
| Sunrise azimuth zero | plus/minus 5 degrees | split pinion collar | collar/shaft line |
| Sunset azimuth zero | plus/minus 5 degrees | split hand hub | hub/tube line |

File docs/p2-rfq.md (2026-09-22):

# P2 CNC Request-for-Quotation Package

Quote one Rev-A prototype set plus separate unit prices for a second set. Quote
P2-120 through P2-122 first as a coupon lot and the remaining custom parts as a
production lot released only after coupon approval.

## Files and precedence

Use the PDFs for dimensions, GD&T, notes, material, finish, and inspection. Use
STEP for 3D form and DXF for flat profiles. CSV cam profiles are independent
inspection data. STL is preview-only. All supplied files must match the package
SHA-256 list.

## Requested quote breakdown

1. POM-C coupon lot: P2-120 and P2-121.
2. POM-C production cams: P2-101 and P2-102.
3. 6061-T6 milled parts: P2-103 through P2-109, P2-122, and P2-124 through
   P2-126, with anodize shown separately.
4. 303 stainless turned parts: P2-110 through P2-113, P2-123, P2-127, and
   P2-128.
5. Laser/router parts: P2-115 through P2-119.
6. Inspection report for interfaces I-01 through I-05 and shaft runout.
7. Material certificates, programming/setup charges, shipping, tax, lead time,
   quote validity, and remake policy as separate entries.

## Supplier questions

- Can you hold a 0.05 mm free-form profile relative to a 32 H7 bore in POM-C?
- What stock conditioning and stabilization do you use before final profiling?
- Will the same machine setup finish pilot, datum hole, and profile?
- Can you return measured profile data or a CMM report at 16 date stations?
- What bearing-fit masking method is used during anodize?
- Are any CAD features ambiguous or economically dominant?

No substitution, profile smoothing, unit conversion, or unexplained CAM
optimization is authorized. Supplier shall request disposition before deviating.

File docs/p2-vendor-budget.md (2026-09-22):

# P2 Vendor Shortlist and Budgetary Estimate

Status: Current-market review, 2026-09-21
This is a sourcing recommendation and planning estimate, not a quotation. No
files have been uploaded and no vendor has been contacted or authorized.

## Recommended sourcing split

### Precision CNC and inspection

Send the same RFQ to **Xometry**, **Protolabs Network**, and one local ISO 9001
job shop. Xometry publicly offers 6061, stainless, and acetal with specified
tolerances as tight as plus/minus 0.001 inch when called out. Protolabs Network
explicitly lists CNC-machined POM-C and provides instant quotation/DFM review.
The default platform tolerances are looser than the cam profile requirement, so
the 0.05 mm profile, 32 H7/h6 register, stabilization, and inspection report
must be treated as custom quote requirements—not platform defaults.

- Xometry CNC capability: <https://www.xometry.com/capabilities/cnc-machining-service/>
- Protolabs Network POM capability: <https://www.hubs.com/cnc-machining/plastic/pom-delrin/>

Recommendation: release only P2-120 through P2-122 first. Prefer the supplier
that accepts the common-datum setup and returns actual measurements, even if it
is not the lowest bidder. Then keep the cams and hubs with that same supplier.

### Flat guard and hands

**SendCutSend** is the first-choice benchmark for P2-115, P2-118, and P2-119.
Its published materials include 4.5 mm (0.177 inch) CNC-routed polycarbonate and
1.6 mm (0.063 inch) 5052-H32 aluminum. Its published laser/routing tolerance is
plus/minus 0.005 inch, suitable for these non-datum flat parts.

- Materials and thicknesses: <https://sendcutsend.com/materials/>
- Sheet-cutting tolerances: <https://sendcutsend.com/services/sheet-cutting/>

### Functional dials

**Front Panel Express** is the preferred benchmark for P2-116/P2-117 because it
combines CNC panel machining with engraving or UV print and live itemized
pricing. Use 2.5 mm anodized aluminum; its published capacity at that thickness
comfortably includes the 360 mm azimuth dial. Upload the DXF and request only
functional markings—decorative artwork is not part of P2.

- Services and live pricing: <https://www.frontpanelexpress.com/service>
- Aluminum size capability: <https://www.frontpanelexpress.com/downloads/FPE/Aluminum-Datasheet.pdf?v2=>

### Gears, racks, and frame

Use **KHK USA** for the critical module-1 gears: SS1-15 (8 mm bore) for the two
15-tooth elements, SS1-30B (8 mm bore) for sunrise input, SS1-80 with a qualified
bushing for azimuth, and an opposite-hand module-1 miter pair. KHK publishes
JIS grades and backlash; its ground SSG1-15 was listed at USD 40.48 at review.
Use **SDP/SI** or KHK for module-1, 20-degree racks; SDP/SI listed a 500 mm steel
rack at USD 64.64 and a nylon rack at USD 87.96. Cut after receipt and inspection.

- KHK 15-tooth gear: <https://www.khkgears.us/catalog/product/SSG1-15>
- KHK module-1 spur catalog: <https://www.khkgears.us/media/1019/01-spur.pdf>
- KHK module-1 miter catalog: <https://khkgears.net/pdf/2025/miter-gears.pdf>
- SDP/SI steel rack: <https://shop.sdp-si.com/ksrf1-500.html>

Use **80/20 20-2040** or a dimensionally equivalent metric profile for the
frame. The official profile is 20 x 40 mm 6063-T6, clear anodized, with six
slots and published CAD.

- 80/20 20-2040: <https://8020.net/20-2040.html>

## Budgetary cost range for one prototype

| Package | Expected low | Expected high | Basis / main uncertainty |
|---|---:|---:|---|
| Coupon lot P2-120..122 | USD 300 | USD 800 | inspection/setup dominates |
| POM-C cams and two hubs | 900 | 2,200 | 0.05 profile, stabilization, CMM report |
| Aluminum plates/levers/carrier | 700 | 1,800 | setup and anodize |
| Four stainless shafts/tube | 350 | 900 | journals, concentricity, low quantity |
| Guard and four hands | 180 | 450 | routing/laser, deburr, shipping |
| Three functional dials | 550 | 1,200 | engraving/UV print and large diameter |
| Gears, racks, rails, bearings, springs | 750 | 1,600 | gear grade and linear-rail choice |
| Frame and general hardware | 250 | 550 | cut service and fasteners |
| Shipping, inspection, remake reserve | 600 | 1,500 | multi-vendor freight and first article risk |
| **Planning total** | **4,580** | **11,000** | before tax; no assembly labor |

A reasonable authorization budget is **USD 7,500**, with only USD 300-800
released for the coupon gate initially. The low end assumes automated online
quoting and mostly standard inspection; the high end assumes domestic quick-turn
work, formal inspection, and one correction cycle. Consolidating all precision
parts at one inspected shop may cost more initially but reduces datum-transfer
and remake risk.

## Route comparison

| Route | Cam / precision strategy | Expected total | Planning lead time | Tradeoff |
|---|---|---:|---:|---|
| Minimum-cost hybrid | CNC POM-C cams with standard inspection; online-cut guard/hands; commercial-grade racks/gears | USD 4,600-6,500 | 3-6 weeks after coupon approval | Highest dependence on incoming inspection and preload tuning; remake reserve essential |
| Recommended accuracy | Stabilized POM-C cams/hubs in one setup with 16-station CMM report; ground 15T gears; inspected rails; anodized datum plates | USD 7,500-11,000 | 5-10 weeks after coupon approval | Best balance of low cam friction, inspectability, and one-off precision |
| Aluminum-cam alternate | 6061-T6 cams, hard anodized after profile verification, metal rollers | add USD 1,500-3,000 | add 2-4 weeks | More dimensionally stable during machining, but greater inertia/noise and anodize thickness must be compensated; not automatically more accurate |

POM-C remains the release material because its low friction, machinability, and
low moisture uptake suit the lightly loaded follower. POM-H/Delrin is easier to
source but is a controlled substitution because dimensional behavior differs.
Aluminum is a contingency when a supplier will not certify the 0.05 mm POM-C
profile. SLS/MJF nylon, SLA resin, laser-cut stacked cams, and consumer printing
are not precision production alternatives for P2; they are useful only for
fit/mock-up parts and cannot satisfy the profile/runout allocation without new
qualification.

Lead times are planning ranges inferred from the reviewed suppliers' published
instant-quote/stock lead-time model and low-volume prototype practice; actual
lead time begins only after drawing review and coupon acceptance. Shipping,
tax, import duty, and assembly labor are excluded. Before routing live quotes,
confirm delivery country/postal code, quantity, budget ceiling, and required
in-hand date.

## Quote comparison rules

1. Normalize shipping, tax, finish, inspection, and setup before comparing.
2. Reject substitutions from POM-C to POM-H unless thermal/moisture behavior is
   reviewed and Decision 0005 is revised.
3. Reject default-tolerance quotes that do not acknowledge the critical drawing
   notes and interface table.
4. Score dimensional evidence, communication, and remake policy above lead time.
5. Do not release production cams until the coupon report is reviewed.

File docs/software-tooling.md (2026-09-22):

# Software and Tooling

Status: Implemented for P0/P1/P2

Date: 2026-09-21

## Required now

The host needs only:

- Python 3.12; and
- Git.

`scripts/bootstrap.ps1` creates `.venv` in the checkout and installs the pinned
free Python dependencies from `requirements-lock.txt`. Nothing is installed
system-wide.

## P0/P1 implementation

| Task | Tool |
|---|---|
| NREL SPA reference | pvlib 0.13.1 |
| Independent ephemeris validation | Skyfield 1.53 + JPL DE421 |
| Arrays/tables/interpolation | NumPy 2.2.6, pandas 2.3.2, SciPy (pvlib dependency) |
| Plots | Matplotlib 3.10.6 |
| Reproducible mesh generation | Shapely 2.1.1, trimesh 4.8.1, mapbox-earcut 1.0.3 |
| Automated verification | pytest 8.4.2 |

## P2 additions

P2 uses CadQuery 2.6.1 and its pinned open-source OCP stack to produce STEP and
STL, plus ezdxf 1.4.2 for machinist-facing DXF files. These install only in the
project-local `.venv`; no system-wide CAD installation is required.

`python -m solar_watch.cli generate-p2 --root .` regenerates the 28 custom
parts, top-level assembly STEP, profiles, layout plot, manifest, and hashes.
`scripts/build_p2_pdfs.py` uses ReportLab from the Codex bundled document
runtime to generate the three release PDFs. Poppler renders every PDF page for
visual QA. A non-Codex user may install the open-source `reportlab`, `pypdf`,
and `pdfplumber` packages in a separate project-local environment if rebuilding
PDFs; the CNC geometry and software verification do not require them.

STEP and DXF writers may vary non-geometric headers between processes. Release
SHA-256 files identify the exact reviewed deliverables. The clean verifier
regenerates P2 in a temporary directory and compares STL/profile bytes, DXF
model-space entities, assembly STEP solid count/volume/bounds, the full motion
sweep, and the analysis JSON. Thus regeneration checks geometry and engineering
content without mistaking volatile interchange metadata for a design change.

The committed STL files are generated directly from the compensated follower
geometry in `src/solar_watch/cam.py`. No desktop CAD installation is required to
reproduce P1.

## Proposed free toolchain

The exact CAD route should be selected after the numerical model and first cam
representation are understood. The current preference is:

| Task | Preferred free option | Notes |
|---|---|---|
| Reference calculation | Python | Already installed |
| Numerical arrays and analysis | NumPy/SciPy | Python packages; install only when the model begins |
| Plots and diagnostic figures | Matplotlib | Python package |
| Parametric solid CAD | FreeCAD | Useful for assemblies, shafts, frames, and drawings |
| Scripted mechanical CAD | CadQuery | Good candidate for reproducible generated solids |
| Direct mesh generation | Python plus a mesh library | Useful for mathematical cam surfaces |
| Slicing | OrcaSlicer or PrusaSlicer | Choose whichever matches the available printer workflow |
| Source control | Git | Already installed |

OpenSCAD remains an alternative for simple parametric parts, but complex smooth
surface cams and assemblies are likely to be easier to manage with CadQuery,
FreeCAD, or direct mesh generation.

## Installation policy

- Do not install software merely because it might become useful.
- Keep the mathematical model independent of a proprietary CAD package.
- Generate derived geometry from version-controlled scripts.
- Record tool versions once they begin affecting output files.
- Prefer file formats that can be regenerated over manually repaired meshes.

## Later phases

A slicer is required to print but is intentionally not selected until the
printer is known. FreeCAD remains a possible later assembly-CAD tool, but P1
does not require it. Any future desktop or system-wide installation must be
discussed before it is required.

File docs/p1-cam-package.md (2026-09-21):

# P1 Fixed-Latitude Cam Package

Status: Digitally validated, awaiting physical print results

Latitude: `42.1 deg N`

Part revision: A

## Scope

P1 contains two independent radial plate cams driven by a manually positioned
annual shaft:

1. daylight duration; and
2. sunrise azimuth.

It deliberately contains no variable-latitude surface, time differential,
finished dial, mirrored sunset mechanism, or integrated P2 frame.

## Follower model

Both profiles are generated for a translating radial roller follower:

- roller: 625 bearing, `16 mm` outside diameter (`8 mm` radius), `5 mm` bore;
- follower centerline: passes through the cam axis;
- translation: an MGN12H carriage on a radial 150 mm rail, or an equivalent
  low-play guide;
- preload: extension spring pulling the carriage toward the cam, nominally
  `1..3 N` over the full stroke;
- measurement: `0.01 mm` digital indicator parallel to the rail;
- prescribed setting direction: rotate the marked cam face clockwise to move
  forward through the year.

The generated contact surface is the inward normal offset of the desired
roller-center pitch curve. It is not a raw polar plot. Maximum pressure angles
are `18.42 deg` (daylight) and `17.62 deg` (azimuth), comfortably below the
provisional 30-degree P1 limit.

## Scale and geometry

| Parameter | Daylight cam | Sunrise-azimuth cam |
|---|---:|---:|
| Conversion datum | 545 min | 55 deg |
| Pitch radius at datum | 48.0 mm | 48.0 mm |
| Scale | 0.13 mm/min | 0.70 mm/deg |
| 2025 input range | 546.252..915.290 min | 56.685..121.536 deg |
| Follower travel | 47.975 mm | 45.395 mm |
| Cam surface radius | 40.163..88.138 mm | 41.179..86.575 mm |
| Maximum pressure angle | 18.42 deg | 17.61 deg |
| Thickness | 8.0 mm | 8.0 mm |
| Nominal 608 bearing bore | 22.2 mm | 22.2 mm |

The conversion from measured roller-center pitch radius `r` is:

```text
daylight_minutes = 545 + (r_mm - 48) / 0.13
sunrise_azimuth_degrees = 55 + (r_mm - 48) / 0.70
```

A `0.01 mm` indicator increment corresponds to `0.077 min` or `0.014 deg`.
Those are instrument increments, not finished-part accuracy claims. With a
finished profile error of `±0.13 mm`, the equivalent errors are `±1.0 min` and
`±0.19 deg`. At `±0.20 mm`, they are `±1.54 min` and `±0.29 deg`. P1 exists to
measure which tolerance is repeatable with the user's printer and finishing
process.

## Date coordinate and datums

- The central `22.2 mm` bore accepts a 608 bearing; the 8 mm steel shaft runs in
  that replaceable bearing, never directly in a printed precision hole.
- The `3.2 mm` hole on the positive-X ray is the Jan 1 angular datum.
- With the Jan 1 hole pointing at the follower, the cam is at Jan 1. Rotate the
  marked face clockwise by `360/365 = 0.986301 deg` per day to advance the date.
- One small ID hole opposite the datum identifies the daylight cam; two identify
  the azimuth cam. Filenames also carry latitude and revision.
- The SVG red ray is the inspection datum and is not decorative dial artwork.

Use a shaft collar and washer for axial retention. Do not clamp through or
finish away the Jan 1 datum hole.

## Adjustment provisions

P1 uses an adjustable measurement chain instead of baking calibration error
into the cam:

- **Bearing fit:** print the five-size 608 coupon first and select the bore that
  gives a seated, removable bearing without visible distortion. Revision A
  printables use 22.2 mm; change `bearing_bore_mm` and regenerate if the coupon
  selects another size.
- **Runout:** the constant-radius coupon isolates bearing/bore/shaft runout from
  the astronomical profile.
- **Zero:** translate or zero the indicator at the Jan 1 datum. The indicator
  mount must retain at least ±5 mm of coarse adjustment.
- **Span:** use the two seasonal extrema to fit an affine measured-displacement
  calibration. Record both the nominal conversion and measured slope; do not
  edit the STL by hand.
- **Phase:** loosen the manual date pointer or shaft collar, align Jan 1's datum
  hole to the follower centerline, and retighten. No cam reprint is needed.
- **Preload:** move the spring anchor among baseboard holes or use a turnbuckle;
  target reliable contact with the smallest force that avoids lift-off.

## Tolerances

| Feature | Revision A target | Verification |
|---|---:|---|
| Finished contact profile | ±0.13 mm desired; ±0.20 mm initial limit | indicator versus reference dates |
| Constant-radius total indicated runout | ≤0.10 mm desired | runout coupon, full revolution |
| Bidirectional hysteresis | ≤0.08 mm desired | same date from both directions |
| Cam flatness | ≤0.30 mm over part | surface plate/straightedge and feeler gauge |
| Bearing fit | coupon-selected, no visible ovalization | hand fit and runout test |
| Follower-to-axis alignment | ±0.5 mm lateral | ruler/square inspection |

The one-minute integrated time target is not claimed until physical P1 results
show a repeatable `±0.13 mm` or better daylight profile. Azimuth has substantial
margin against its one-degree requirement.

## Segmentation and printer envelope

Revision A is intentionally one piece. The minimum rotated rectangles are about
`128.3 x 135.1 mm` (daylight) and `127.8 x 132.5 mm` (azimuth), and the largest
radius is under 89 mm. Both fit the repository's provisional 220 mm square bed
with ample room and avoid joint runout, phase error, and extra fasteners.

If the available bed is smaller than 150 mm after brim allowance, do not slice
the STL arbitrarily. A future segmented variant should use at least two dowel
datums per joint, radial fasteners outside the 608 bearing, and a printed joint
coupon; its assembled surface must be requalified with the same runout and
profile tests. No segmented file is included because it would reduce accuracy
without helping the assumed printer.

## Generated deliverables

`printables/p1/` contains:

- both watertight STL cams;
- matching 1:1 SVG inspection profiles;
- dense profile CSV files;
- a constant-radius runout STL;
- a 608-bearing fit STL with 21.9, 22.0, 22.1, 22.2, and 22.3 mm holes from
  left to right when the long edge is horizontal;
- `manifest.json` with generator inputs and mesh checks; and
- `SHA256SUMS.txt` for file-integrity checks.

All are regenerated by `scripts/regenerate.ps1`; the source of truth is Python,
not the mesh.

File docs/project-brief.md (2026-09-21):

# Project Brief

Status: Draft v0.1  
Date: 2026-09-21

## Purpose

Create a visually understandable mechanical astronomical display, built
primarily from 3D-printed parts, that represents:

1. local sunrise time;
2. local sunset time;
3. sunrise azimuth; and
4. sunset azimuth.

The finished demonstrator should make the relationship between season,
latitude, daylight duration, and sunrise direction visible through physical
motion. The intended scale is a wall-mounted or tabletop mechanism with a
maximum frontal envelope of approximately 36 by 24 inches.

## Product idea

The display has three solar dials:

- a sunrise-time dial;
- a sunset-time dial; and
- a 360-degree compass dial carrying separate sunrise and sunset hands.

An optional conventional clock movement may provide current local time as a
fourth display. That clock is not part of the astronomical computation in the
initial prototypes.

The preferred final mechanism accepts date and latitude. A manually established
time reference may be used to avoid mechanically calculating longitude, civil
time zone, daylight-saving rules, and the equation of time in the first version.

## Development principle

Software will be used to calculate and validate the astronomical functions and
to generate printable cam geometry. The finished display may remain entirely
mechanical in operation. Using software during design is not considered an
electronic implementation of the final mechanism.

The development sequence is:

1. verified numerical reference model;
2. fixed-latitude cam and follower test;
3. full dial and summing-mechanism test;
4. variable-latitude surface cams;
5. integrated demonstrator; and
6. refinement for repeatable fabrication.

## Initial success criteria

The project is successful when an integrated demonstrator:

- operates across latitudes from 60 degrees south through 60 degrees north;
- indicates standardized astronomical sunrise and sunset azimuth within one
  degree of the reference model;
- indicates standardized sunrise and sunset time within one minute of the
  reference model as a design target;
- makes five-minute time differences and five-degree angle differences readily
  visible to a user;
- can be fabricated with commonly available 3D printers and inexpensive metal
  shafts, bearings, fasteners, and springs; and
- can be calibrated without reprinting the entire mechanism.

The distinction between calculation accuracy, mechanical indication accuracy,
repeatability, and human readability is intentional. Each will be measured
separately.

## Out of scope for the first prototypes

- Wristwatch-scale packaging
- Automatic longitude detection
- Automatic daylight-saving rules
- GPS or phone connectivity
- Actual terrain or building-horizon modeling
- Guaranteed agreement with visually observed sunrise in unusual atmospheric
  conditions
- Polar-day and polar-night behavior beyond 60 degrees latitude
- Decorative finishing suitable for a production object

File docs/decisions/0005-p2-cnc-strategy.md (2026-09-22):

# Decision 0005: P2 CNC Materials and Datum Strategy

Status: Accepted for detailed design

Date: 2026-09-21

## Context

The P1 profiles were generated for consumer printing, including printer-fit
bearing bores. P2 parts are intended for accurate CNC manufacture and possible
reuse in a fixed-latitude display. Manufacturing drawings must distinguish
functional contour accuracy from ordinary overall size tolerance.

## Decision

- Cam profiles: black or natural POM-C/acetal, nominally `10 mm` thick.
- Cam hubs, local module plates, bearing blocks, and critical levers: 6061-T6
  aluminum unless a purchased component is selected.
- Shafts and dowels: ground stainless or hardened steel stock.
- Guards: clear polycarbonate; nonprecision functional dial panels may use
  aluminum composite panel or engraved acrylic after the geometry is frozen.
- Cam-to-hub location: precision pilot plus one asymmetric indexing dowel; bolts provide
  clamp load but do not define phase.
- Cam contour: basic geometry from the controlled DXF/STEP, profile tolerance
  `0.05 mm` relative to the hub pilot datum, with no uncontrolled edge break on
  the follower surface.
- Cam faces: parallel within `0.05 mm`; contact edge perpendicular to datum face
  within `0.05 mm` over thickness; target machined finish `Ra 1.6 micrometre` or
  better on the follower surface.
- Critical bores and dowel holes receive explicit limits on drawings; vendor
  general tolerances apply only where no specific tolerance is shown.

## Alternatives considered

- SLA offered smooth surfaces but introduced cure shrinkage, long-term resin
  behavior, and support-orientation sensitivity.
- SLS and MJF offered durable nylon but their normal dimensional tolerance and
  grainy surface were poorly matched to the one-minute cam target.
- Aluminum cams offered stiffness and stable machining but increased rotating
  mass, follower wear, price, and noise without improving the reference data.
- Direct bearing bores in the cam made the profile disposable with the bearing
  fit and provided no robust phase interface for P2 reuse.

## Consequences

- P1 print-fit coupons do not set P2 CNC bore dimensions.
- The cam hub becomes a separate controlled part.
- Quote packages must request contour inspection, not merely a generic overall
  tolerance.
- Physical conformance and wear remain pending until parts are manufactured.

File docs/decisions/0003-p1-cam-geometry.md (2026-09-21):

# Decision 0003: P1 Cam and Follower Geometry

Status: Accepted provisionally for first print

Date: 2026-09-21

## Context

P1 must maximize measurable motion while fitting a consumer printer and must
separate surface error, runout, hysteresis, and calibration.

## Decision

Use one-piece 8 mm plate cams with a translating 16 mm roller follower on a
radial linear rail. Encode daylight at 0.13 mm/min and sunrise azimuth at
0.70 mm/degree from a 48 mm pitch-radius datum. Locate each cam on a replaceable
608 bearing. Provide a bearing-fit coupon, constant-radius runout coupon, Jan 1
datum, distinct physical ID-hole patterns, and affine zero/span calibration.

## Alternatives considered

- sliding followers, which add friction and finish sensitivity;
- 22 mm 608 bearings as rollers, which increase offset and envelope;
- smaller scales, which reduce measurable resolution;
- larger or segmented cams, which add joint/runout error; and
- manually edited CAD profiles.

## Consequences

- One minute of daylight is 0.13 mm and one degree is 0.70 mm.
- The cams fit the provisional 220 mm printer and do not need segmentation.
- The daylight one-minute target remains a physical test target, not a claim.
- A printer selecting a non-22.2 mm fit coupon requires regeneration and a new
  part revision, never local mesh editing.

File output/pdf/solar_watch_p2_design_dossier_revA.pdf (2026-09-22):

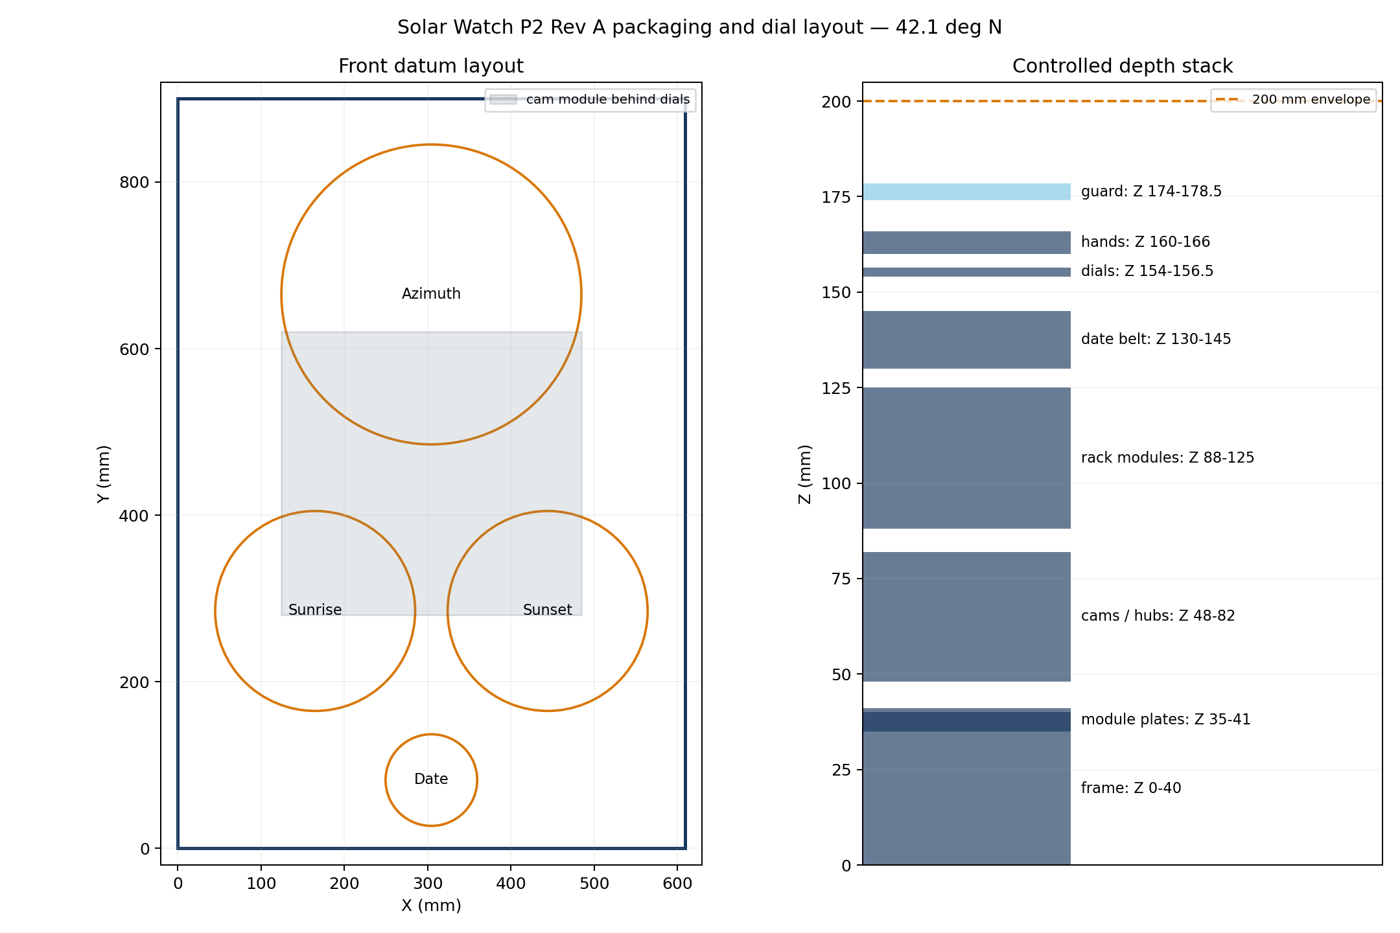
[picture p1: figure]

Solar Watch | P2 DESIGN DOSSIER | Rev A | 42.1 deg N | Page 1

# Solar Watch P2 Design Dossier

## CNC-ready fixed-latitude astronomical display

REV | A | LATITUDE | 42.1 deg N | RELEASE | FOR QUOTATION / PHYSICAL TEST PENDING

## Release statement

This release completes the digital P2 design and quotation package. Numerical results and kinematics are verified. Fabrication-dependent accuracy remains explicitly pending until the coupon, module, and integrated tests are completed.

# P0 Numerical Reference and Validation

Status: Complete for P1

Reference year: 2025 (365 days)

Latitude: +42.1 deg

Longitude used for timestamps: 0 deg (UTC; it does not affect daylight duration)

## Frozen convention

The reference event is the topocentric solar-center crossing of -0.833 deg at an ideal, unobstructed sea-level horizon. Azimuth is clockwise from true north. The reference year is deliberately non-leap so the P1 date cam has 365 equal daily increments. A future annual drive must address leap years; that is not part of P1.

The production calculation in src/solar_watch/model.py uses pvlib 0.13.1's Python implementation of the NREL Solar Position Algorithm (SPA). SPA supplies the initial event estimate; a vectorized root refinement then locates the topocentric geometric-elevation crossing at exactly -0.833 deg. An automated test checks every sunrise and sunset to within 0.000001 deg of that altitude.

NREL describes SPA as a high-accuracy solar position algorithm with a reported solar-position uncertainty of about ±0.0003 deg:

- [NREL SPA technical report](https://www.nrel.gov/docs/fy08osti/34302.pdf)
- [pvlib SPA
implementation](https://pvlib-python.readthedocs.io/en/stable/reference/generated/pvlib.solarposition.spa_python.html)

## Independent validation

src/solar_watch/validation.py independently computes every event in 2025 with Skyfield 1.53 and the JPL DE421 planetary ephemeris. Skyfield's documented sunrise definition is a solar center 0.8333 deg below the horizon; the script explicitly requests -0.833 deg to match this project:

- [Skyfield almanac documentation](https://rhodesmill.org/skyfield/almanac.html)

The committed JPL-derived table makes the 365-day comparison available offline. It can be refreshed with solar-watch validate-ephemeris; the first refresh downloads de421.bsp into .cache/skyfield, not into a system location.

Quantity | Maximum absolute difference | Requirement
Sunrise event time | 0.002153 min (0.129 s) | 0.1 min
Sunset event time | 0.002144 min (0.129 s) | 0.1 min
Daylight duration | 0.000564 min (0.034 s) | derived diagnostic
Sunrise azimuth | 0.000121 deg | 0.1 deg
Sunset azimuth | 0.000094 deg | 0.1 deg

The model passes ACC-001 and ACC-002 for the P1 latitude and reference year. The full -60..+60 deg domain is boundary-tested but not claimed as a completed P3 validation sweep.

## Outputs

- data/reference_42p1N_2025.csv: the production full-year table.
- data/skyfield_de421_42p1N_2025.csv: independent full-year events.
- data/validation_errors_42p1N_2025.csv: row-by-row differences.
- artifacts/plots/p0_reference_42p1N_2025.png: annual functions.
- artifacts/plots/p0_validation_errors_42p1N_2025.png: error sweep.

The reference table retains timestamps and unrounded values. Cam generation uses those values directly; display rounding is never fed back into geometry.

## Symmetry finding

Using the event-specific solar positions, actual sunset azimuth differs from 360 deg - sunrise azimuth by at most 0.277 deg in 2025. That is below the one-degree P1/P2 azimuth allocation, so mirrored sunset indication remains a valid later architecture choice. P1 nevertheless generates only the requested sunrise-azimuth cam and does not implement the P2 mirror mechanism.

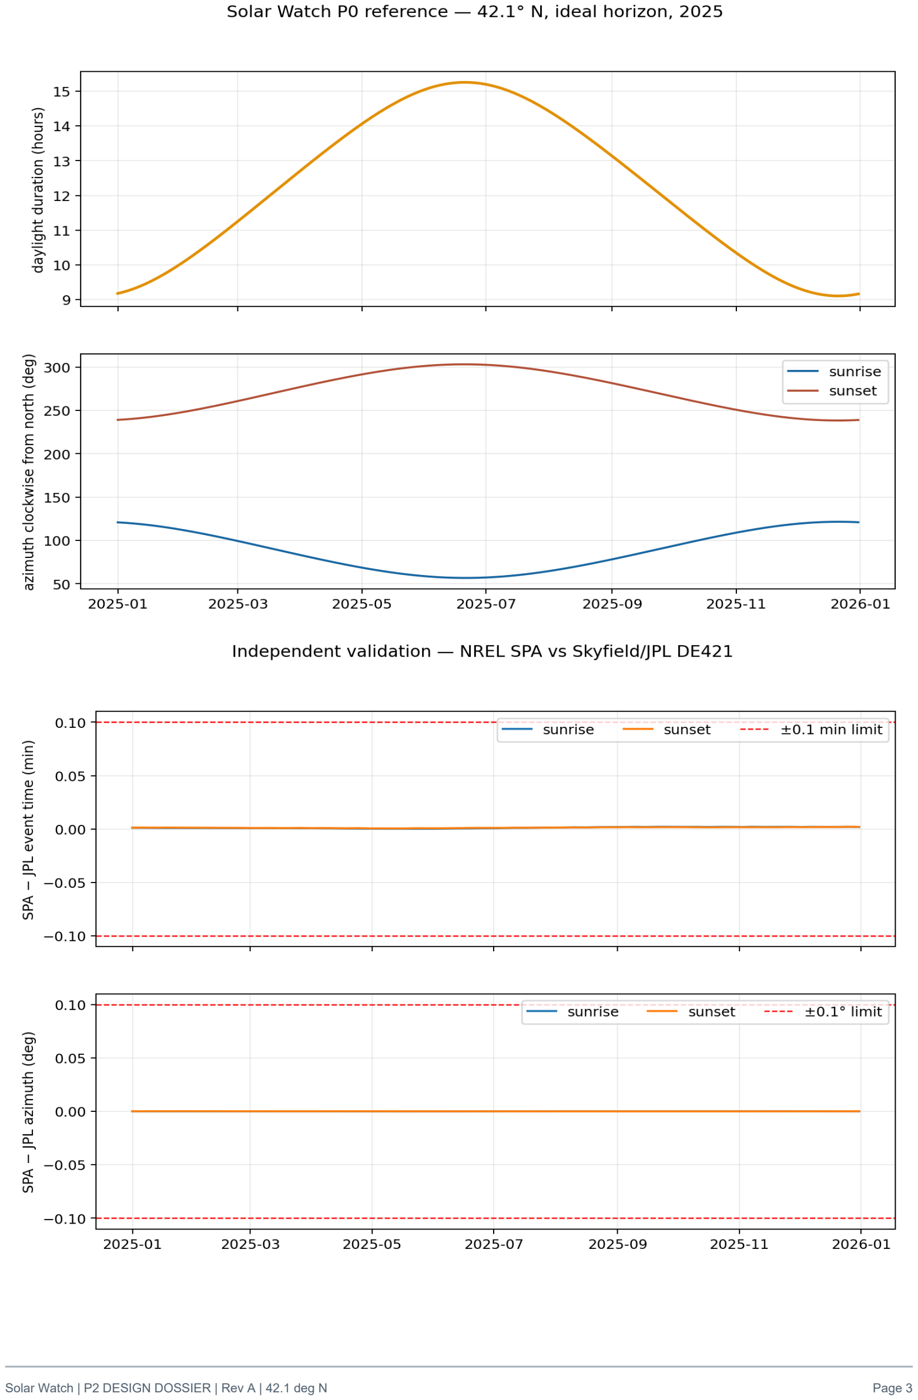
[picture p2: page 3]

# P2 Fixed-Latitude Design Basis

Status: Released for quotation, Rev A Latitude: 42.1 degrees north Units: millimetres unless noted

## Scope and evidence boundary

P2 is a full-size, manually set, fixed-latitude astronomical display. One date input drives the P0-validated daylight-duration and sunrise-azimuth cams. The operator separately sets sunrise time. The mechanism displays sunrise time, mechanically calculates sunset time, and displays mirrored sunrise and sunset azimuths. The package intentionally stops before variable latitude, automatic civil-time correction, decorative dial artwork, or the P3/P4 mechanisms.

The solar model, cam profiles, linkage equations, nominal clearances, and CAD envelopes are digitally verified. Cutting accuracy, bearing fits, friction, preload, backlash, stiffness, and achieved indication error remain physical acceptance items. Decision 0006 records the deliberate P1 test bypass.

## Display and frame

The controlled external envelope is 609 wide by 900 high by 200 deep. A 20-series metric T-slot perimeter supports three removable 6 mm 6061-T6 module plates and a 4.5 mm clear polycarbonate guard. The front layout uses these dial centers from the lower-left corner:

Display | Center X | Center Y | Diameter | Minor division
Sunrise azimuth / sunset azimuth | 304.5 | 665 | 360 | 5 degrees
Sunrise time | 165 | 285 | 240 | 5 minutes
Sunset time | 444 | 285 | 240 | 5 minutes
Date setting | 304.5 | 82 | 110 | monthly reference

The five-minute time spacing is 5.236 mm on the dial rim. Five azimuth degrees occupies 15.708 mm. The functional scales are engraved or UV printed on 2.5 mm anodized aluminum; decorative artwork remains outside P2.

## Cam stack and date datum

Both cams retain the P1 translating 16 mm roller geometry and validated scales:

Cam | Datum | Follower scale | Pitch radius | Surface radius range
Daylight duration | 545 min | 0.1308997 mm/min | 48 mm nominal | generated manifest
Sunrise azimuth | 55 degrees | 0.6981317 mm/degree | 48 mm nominal | generated manifest

Each 10 mm POM-C cam pilots on a 32 H7/h6 metal hub register, clamps with three M5 screws on a 40 mm bolt circle, and has a 4 mm indexing dowel at radius 20, 60 degrees counter-clockwise from the January 1 profile ray. The pair shares a 12 mm keyed date shaft. A split-clamp shaft collar gives continuous date phase adjustment of at least plus/minus 3 degrees after the dowel-defined nominal phase is established. Rotate the date control clockwise to advance the calendar while the followers remain on the positive-X datum ray.

The visible date control at (304.5, 82) drives the common cam shaft at (224.5, 375) through two 30-tooth HTD-5M pulleys and one 760 mm, 15 mm-wide belt. Equal tooth counts preserve 1:1 date phase. A smooth-back idler on a slot sets 10 to 20 N static belt tension and provides assembly tolerance. The date phase collar is downstream of the belt so belt indexing does not alter the cam datum. The belt is always approached clockwise during setting; bidirectional phase hysteresis is measured separately.

Cam faces are finish-machined together to 10.00 plus/minus 0.03 thickness. Profile tolerance is 0.05 relative to datum A (hub pilot); face parallelism and shaft-axis perpendicularity are 0.05. The follower surface is Ra 1.6 micrometre or better, with edges broken 0.2 maximum. Do not polish across the datum pilot.

## Daylight-to-sunset mechanism

The sunrise knob drives a 15 mm pitch-radius pinion and the sunrise hand. Its rack travel is 94.248 mm for one 12-hour revolution. The P2 daylight cam directly encodes the required rack scale, so the daylight calibration lever is nominally 1:1; its annual rack range is approximately 48.31 mm.

Two opposed module-1 input racks constrain a freely rotating module-1, 15-tooth planet pinion carrier to their arithmetic mean. Carrier translation therefore equals one half of the summed rack positions. A third rack attached to the carrier drives a fixed-axis module-1, 15-tooth output pinion; its 7.5 mm pitch radius converts carrier translation back to the full angular sum. The sunset phase clamp removes the constant 545-minute cam datum. Nominal kinematics are:

x_sunrise = 15 rad(0.5 degrees/minute times sunrise_minutes)
x_daylight = 0.1308997 times (daylight_minutes - 545)
x_carrier = (x_sunrise + x_daylight) / 2
sunset_angle = x_carrier / 7.5 + phase

The racks are spring-biased against opposite tooth flanks by a 1 to 2 N extension spring. Rack guides use dry-running polymer bushings; oil is not permitted near POM cams. Carrier end stops provide 3 mm reserve beyond the calculated motion. The sunset zero collar provides plus/minus 15 degrees and the daylight lever slot provides plus/minus 2 percent span adjustment.

## Azimuth mechanism

The P2 azimuth cam directly encodes 0.6981317 mm/degree. Its follower drives a rack through a nominal 1:1 adjustable calibration lever. The rack turns a module-1 pinion with 40 mm pitch radius (80 teeth), so one true azimuth degree produces one output degree. A preloaded 1:1 miter gear pair reverses the sunset output around the north-south meridian. The sunrise hand mounts on an 8 mm inner shaft and the sunset hand on a 14 mm OD by 8.1 mm ID outer tube. Two opposed spring washers remove axial clearance.

The sunrise zero collar allows plus/minus 5 degrees; the lever slot allows plus/minus 2 percent span. The sunset hand has an independent zero clamp so the two hands can be made symmetric at the equinox without disturbing the cam.

Both calibration levers use exact tangent-intersection geometry. A center-pivoted 180 mm lever has separate radial slots on each side. Input and output crosshead pins move on parallel guides at nominal offsets of minus and plus 75 mm, so their displacement ratio equals the ratio of guide offsets. Shifting the output guide from 73.5 to 76.5 mm provides 0.98:1 through 1.02:1 span without trigonometric scale error. Spring-biased slot rollers remove play; the calibrated guide is clamped by two bolts and jam nuts.

## Followers, preload, and bearings

Both cams use sealed 16 mm OD by 5 mm bore track rollers, 7 mm nominal width, on shoulder screws. Each follower has 1 to 3 N positive preload throughout its travel and a mechanical retainer that prevents a disengaged roller from contacting the adjacent cam. All rotating display shafts run in replaceable flanged ball bearings or oil-impregnated bronze bushings located by machined module plates. Printed holes are not precision bearings.

## Mechanical analysis and error allocation

The automated full-year sweep, pressure-angle loads, input torque, shaft/frame deflection, travel, interference clearances, backlash allocations, readability, and root-sum-square error budget are controlled by p2-mechanical-analysis.md. Estimated RSS is 0.768 minute and 0.557 degree against one-minute and one-degree targets. These are design estimates; physical module and integrated sweeps are required before the targets can be claimed.

## Adjustment order

1. Inspect the hub pilot and shaft runout coupons.
2. Set date phase at January 1 with both cam dowels installed.
3. Set daylight and azimuth follower preload to 1 to 3 N.
4. Set daylight lever span using the minimum and maximum reference dates.
5. Set sunset zero at the 545-minute daylight datum.
6. Set azimuth lever span at the two solstice reference points.
7. Set sunrise azimuth zero, then set the reversed sunset hand for symmetry.
8. Lock all jam nuts, witness-mark clamps, and repeat the full sweep.

# P2 Interface Control Document

Status: Released for quotation, Rev A All dimensions are millimetres. CAD is master for profile geometry; this file is master for functional interfaces and acceptance.

## Coordinate system

Front view uses X right, Y up, and Z toward the viewer. The overall origin is the lower-left corner of the 609 by 900 envelope. Cam-fixed profile angle zero is the positive-X January 1 ray. The 4 mm indexing dowel is at radius 20 and 60 degrees counter-clockwise from that ray to avoid the three M5 clamp screws. Positive cam profile angles are counter-clockwise; the installed date knob advances clockwise.

## Controlled interfaces

ID | Interface | Nominal | Fit / tolerance | Verification
I-01 | Cam-to-hub pilot | 32 diameter | H7 cam / h6 hub | bore gauge, micrometer
I-02 | Cam clamp circle | 3 x M5 on 40 PCD | true position 0.10 to I-01 | CMM or pins
I-03 | January 1 datum | 4 reamed at radius 20, 60 deg CCW from profile zero | H7, position 0.05 to I-01 | CMM or height gauge
I-04 | Hub-to-date shaft | 12 diameter keyed | H7 bore, commercial key | plug gauge
I-05 | Cam face stack | 10 each | plus/minus 0.03; parallel 0.05 | micrometer
I-06 | Roller follower | 16 OD x 5 bore | commercial sealed bearing | certificate / measure
I-07 | Time rack/pinion | module 1, 20 degree PA | quality 8 or better | supplier certificate
I-08 | Sunrise pinion | 30 tooth | 15 pitch radius | roll test
I-09 | Differential/output pinions | 15 tooth | 7.5 pitch radius | roll test
I-10 | Azimuth pinion | 80 tooth | 40 pitch radius | roll test
I-11 | Azimuth coaxial shafts | 8 shaft, 14/8.1 tube | 0.05 diametral running clearance | gauges
I-12 | Module plate mounting | M6 clearance | 6.6 diameter | plug gauge
I-13 | Front guard | 585 x 875 x 4.5 | plus/minus 0.5 outline | tape / caliper
I-14 | Overall envelope | 609 x 900 x 200 maximum | must not exceed | assembled measurement
I-15 | Date belt transmission | HTD-5M, 30T:30T, 760 length, 15 width | 1:1; 10-20 N static tension | tension gauge / phase sweep

## Datum scheme for custom parts

- Cams: datum A is the 32 mm pilot axis; B is the rear face; C is the January 1

dowel hole. The generated profile is basic relative to A and C.

- Hubs: A is the 12 mm shaft bore axis; B is the rear flange face; C is the hub

dowel hole. Pilot runout is 0.025 total indicated relative to A.

- Module plates: A is the rear mounting face, B the lower long edge, and C the

left short edge. Bearing and shaft locations are basic from B/C.

- Levers: A is the pivot bore; B is one broad face; C is the roller-slot center

plane. Pivot-to-slot setting is adjustable and locked by two jam nuts.

- Shafts: A is the bearing journal axis; B is the front shoulder. Display hub

runout is 0.025 total indicated relative to A.

## General drawing notes

1. ISO 2768-mK applies unless specifically toleranced.
2. Deburr and break sharp edges 0.2 to 0.5; never roll or hand-blend cam profiles.
3. Aluminum is 6061-T6, clear anodized 8 to 12 micrometres after machining;

mask bearing fits and electrical bonding points.

4. Cams are stress-relieved, machinable POM-C/acetal, black or natural. Machine

both faces in one setup after roughing and allow 24 hours before finishing.

5. Shafts are 303 stainless, ground journals Ra 0.8 micrometre or better.
6. Polycarbonate guard edges are polished only after all holes are complete.

7. Supplier shall return dimensional inspection results for I-01 through I-05

and shaft runout. No material substitution without written approval.

8. STEP controls 3D form. DXF controls flat profiles. PDF drawing notes control

tolerances, finishes, and inspection.

## Assembly stack along Z

The frame rear plane is Z0. Module plates mount at Z35. The cam stack occupies Z48 through Z82 including hubs, spacers, and followers. Rack modules occupy Z88 through Z125. The date belt occupies Z130 through Z145. Dial faces lie at Z154 through Z156.5, hands at Z160 to Z166, and the guard inner face at Z174. The guard outer face at Z178.5 leaves at least 21.5 mm to the 200 mm maximum envelope for fasteners and stand-off variation.

## Module placement in front coordinates

Module / axis | X | Y | Interface
Cam module plate center | 304.5 | 450 | P2-104, 360 x 340
Common cam/date shaft | 224.5 | 375 | local (-80,-75) on P2-104
Date control shaft | 304.5 | 82 | 1:1 HTD link to cam shaft
Time module plate center | 304.5 | 285 | P2-108, 320 x 180
Sunrise shaft | 165 | 285 | local X -139.5 on P2-108
Sunset shaft | 444 | 285 | local X +139.5 on P2-108
Azimuth module / coaxial shaft | 304.5 | 665 | P2-109 center

The cam plate overlaps dial projections only in X/Y; its Z35-to-Z82 mechanism zone is behind the Z154 dial plane. Belt, spring, and fastener-head clearance is confirmed by the mandatory unguarded physical sweep.

## Adjustment provisions

Adjustment | Range | Locking method | Witness mark
Date phase | plus/minus 3 degrees | split hub collar | shaft/hub line
Daylight span | plus/minus 2 percent | slotted lever, two jam nuts | lever scale
Sunset zero | plus/minus 15 degrees | split output collar | collar/shaft line
Azimuth span | plus/minus 2 percent | slotted lever, two jam nuts | lever scale
Sunrise azimuth zero | plus/minus 5 degrees | split pinion collar | collar/shaft line
Sunset azimuth zero | plus/minus 5 degrees | split hand hub | hub/tube line

# P2 Mechanical Analysis and Error Budget

Status: Digitally verified Rev A; fabrication evidence pending

## Full-year sweep

The committed analysis evaluates 365 dates at 48 sunrise settings in 15-minute steps: 17,520 states. The mathematical rack differential reproduces (sunrise + daylight) mod 12 hours with a maximum numerical kinematic error of 2.3e-13 degree. The P0 mirror approximation differs from independently computed sunset azimuth by at most 0.277 degree. The full table is data/p2_full_year_motion_sweep_42p1N_2025.csv.

Travel | Minimum | Maximum | Allocated usable travel
Sunrise input rack | 0.000 mm | 92.284 mm at 11:45 | 100 mm
Daylight input rack | 0.164 mm | 48.471 mm | 55 mm
Carrier output rack | 0.082 mm | 70.378 mm | 78 mm
Azimuth rack | 1.176 mm | 46.451 mm | 55 mm

Each guide receives at least 3 mm end reserve beyond the analyzed range. The sunrise rack additionally accommodates the untested 11:45-to-12:00 setting margin up to the 94.248 mm theoretical full turn.

## Cam contact, force, and input torque

At the maximum specified 3 N follower preload, the daylight cam has 18.52-degree maximum pressure angle, 13.23 mm minimum pitch-curve curvature radius, 1.01 N maximum tangential follower force, and 65.14 N mm maximum ideal cam torque. The azimuth cam values are 17.58 degrees, 33.93 mm, 0.96 N, and 64.76 N mm. Both curvature radii exceed the 8 mm roller radius.

The two worst cam torques plus 40 N mm bearing/collar allowance total about 170 N mm. The date input is designed and acceptance-tested at 250 N mm; a 50 mm radius handwheel therefore requires no more than 5 N hand force and provides a 1.47 torque factor over the calculated nominal worst case. The sunrise input design torque is 75 N mm including 3 N working and 2 N preload forces, or 1.88 N at a 40 mm knob radius. Measure actual torque before installing the dials.

## Deflection

An 8 mm stainless shaft with a 25 mm cantilever under 3 N deflects 0.00041 mm by Euler-Bernoulli beam theory. A 569 mm 20x40 extrusion span loaded at midspan with 10 N on its published weak-axis inertia deflects 0.046 mm. These estimates are below the 0.01 mm shaft and 0.10 mm frame allocations. Joint slip, plate flatness, and mounting compliance remain physical inspection items.

## Clearance and interference

Automated planar and depth checks establish:

Check | Result | Requirement
Minimum dial-edge gap | 39.0 mm | at least 20 mm
Guard inner face to hand stack | 8.0 mm | at least 8 mm
Depth margin to 200 mm envelope | 21.5 mm | at least 20 mm
Minimum cam profile-to-pilot radial wall | 24.16 mm | at least 10 mm
Time / azimuth hand tip margin | 15 / 15 mm | at least 10 mm

The assembly STEP and A01-A03 drawings additionally define module zones. The digital check cannot prove cable, spring, washer, or fastener-head clearance; the build procedure requires an unguarded slow sweep followed by an 8 mm guard clearance gauge check.

## Backlash and hysteresis allocation

Commercial gear catalog backlash is not the achieved system lost motion. The design uses opposed flank springs on all three time racks and axial spring preload on the miter pair. The error budget assumes residual time-rack lost motion of 0.020 mm (0.306 minute at the 7.5 mm output radius), azimuth spur lost motion of 0.020 mm (0.029 degree), and miter lost motion of 0.030 mm at a 10 mm pitch radius (0.172 degree). These are acceptance limits, not vendor default claims. Directional tests must measure them after assembly.

## Combined error budget

Independent terms are combined by root-sum-square for planning. This is not a guarantee because some fabrication errors can be correlated.

Contribution | Time, min | Azimuth, deg
P0 numerical reference | 0.0022 | 0.00013
0.05 mm cam profile | 0.382 | 0.072
0.025 mm hub runout | 0.191 | 0.036

Contribution | Time, min | Azimuth, deg
0.020 mm follower/linkage | 0.153 | 0.029
Preloaded spur/rack residual | 0.306 | 0.029
Preloaded miter residual | not applicable | 0.172
Calibration residual | 0.200 | 0.150
Reading/parallax | 0.500 | 0.500
Estimated RSS | 0.768 | 0.557
Acceptance target | 1.000 | 1.000

Functional time ticks are five minutes apart, 5.236 mm at the rim; a one-minute interpolation is approximately 1.047 mm. Five azimuth degrees span 15.708 mm; one degree spans 3.142 mm. Hands require a tip width at most 0.6 mm and a dial gap of 1.5 to 3 mm to keep the stated reading allocation credible.

## Reproduction

Run python -m solar_watch.cli analyze-p2 --root .. The command regenerates the full sweep, JSON summary, and mechanical verification plot. Automated tests assert kinematic exactness, travel coverage, clearance, deflection, RSS targets, and that physical validation remains marked pending.

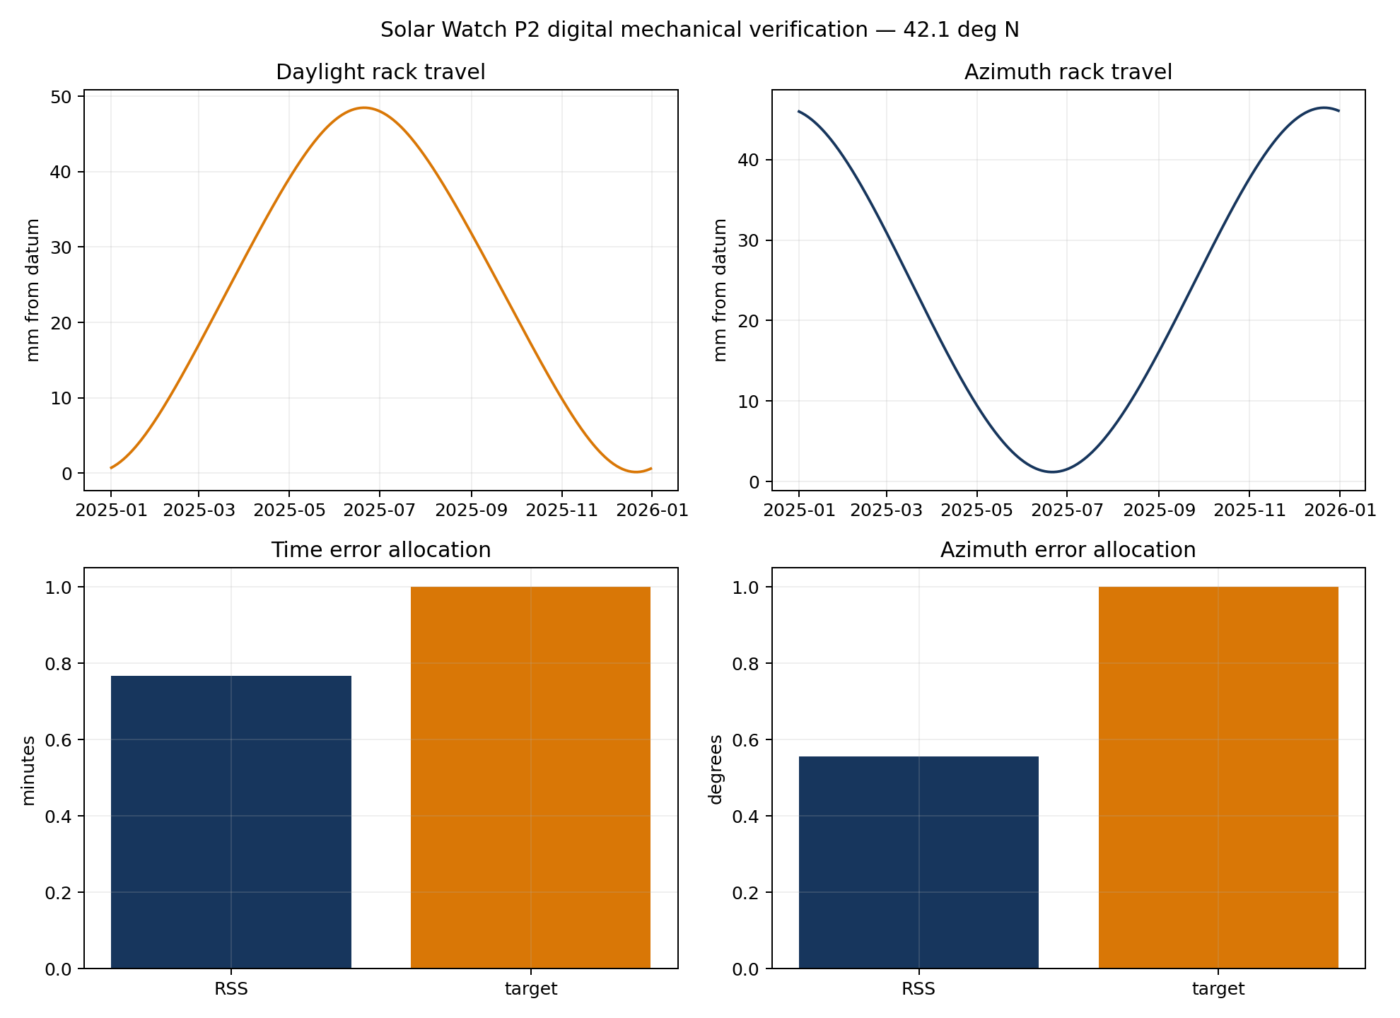
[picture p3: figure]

# P0/P1/P2 Verification Matrix

Requirement / deliverable | Evidence | Status
AST-001..004 conventions | model.py, conventions.md, P0 report | Pass by inspection/tests
AST-005 domain reporting | latitude and calendar boundary tests | Pass
AST-006 azimuth symmetry | 365-day mirror-error column; max 0.277 deg | Pass for P1 allocation
ACC-001 event time ≤0.1 min | NREL SPA vs JPL DE421 full-year test; max 0.002153 min | Pass
ACC-002 azimuth ≤0.1 deg | same full-year test; max 0.000121 deg | Pass
ACC-003 one-minute mechanism | physical P1 measurements | Pending physical test; design target only
ACC-004 one-degree mechanism | physical P1 measurements | Pending physical test
ACC-005/006 repeatability/hysteresis | bidirectional print/test procedure | Pending physical test
MEC-003 segmentation | one-piece ~135 mm footprint; documented revision path | Pass for assumed 220 mm bed; printer confirmation pending
MEC-004 positive preload | 1..3 N spring follower assumption and BOM | Pass by design; physical inspection pending
MEC-005 accessible adjustment | indicator zero, affine span, shaft phase adjustments | Pass by design; physical inspection pending
MEC-006/FAB-005 replaceable bearing/shaft | 608 bearing and 8 mm metal shaft | Pass by design; physical inspection pending
FAB-001 consumer printing | watertight STL, ≤135 mm bounding boxes, no support | Digitally pass; physical print pending
FAB-003 identification | filenames, datum/ID hole patterns, revision, manifest | Pass
FAB-004 finish preserves datums | separate center bearing and internal datum hole; procedure | Pass by design
DOC-001/002 build traceability | build-record template | Pass for package; build record pending print
DOC-003 reproducibility | generator, pinned environment, offline verify script | Pass
DOC-004 calibration without CAD edits | coupon/zero/span/phase procedure | Pass by design
DOC-005 decision records | decisions 0001..0003 | Pass
P2-001 shared manual date | keyed common shaft, cam hub/dowel interfaces | Pass by CAD; physical sweep pending
P2-002 manual sunrise input | 30-tooth input pinion and direct sunrise hand | Pass by design; physical pending
P2-003 sunset arithmetic | full-year x 48 sunrise-setting software sweep | Pass digitally; physical pending
P2-004 mirrored azimuth | full-year linkage/mirror test, 1:1 reverser | Pass digitally; physical pending
P2-005 module calibration | three removable plates and module procedures | Pass by design inspection
P2-006 dial sizes | 240 mm time and 360 mm azimuth DXFs | Pass digitally
P2-007 zero/span/phase | ICD adjustment table and range analysis | Pass by design; physical pending
P2-008 CNC definition | STEP/DXF/PDF, datum scheme, material/finish/inspection | Pass package inspection
P2-009 evidence boundary | design basis, procedure, matrix | Pass
P2-010 serviceability | guard-only access and independent plates | Pass by layout; physical review pending
P2 travel and kinematics | 17,520-state full-year sweep | Pass digitally; max time arithmetic error 2.3e-13 deg
P2 pressure/force/torque | generated cam-load and input-torque summary | Pass analysis; physical torque pending
P2 clearance/interference | dial, cam wall, hand, guard, and depth checks | Pass modeled checks; fastener/spring sweep pending
P2 deflection | shaft and weak-axis frame beam estimates | Pass allocation; assembled measurement pending
P2 error budget | numerical/cam/runout/linkage/backlash/calibration/readability RSS | Pass allocation at 0.768 min / 0.557 deg; physical pending

Software passing does not convert pending physical acceptance items into claims. P1 physical validation was deliberately bypassed by Decision 0006. The P2 package is ready for quotation, then coupon manufacture and module-first test.

# Risk Register

Status: P2 Rev A Date: 2026-09-21

Scores use likelihood and consequence from 1 (low) through 5 (high). Priority is their product and is provisional until physical tests begin.

ID | Risk | L | C | Priority | Initial response
R-001 | Cam and follower errors prevent one-minute indication. | 3 | 5 | 15 | CNC POM cam tolerance is 0.05 mm; run P2 pilot-fit and runout coupons before release, then report results without claiming the target prematurely.
R-002 | Backlash causes different answers depending on setting direction. | 3 | 4 | 12 | Spring-preload rack flanks and followers; procedure records bidirectional hysteresis.
R-003 | Variable-latitude surface cams bind or lose follower contact. | 3 | 5 | 15 | Analyze surface slopes; use roller followers; prototype the surface module independently.
R-004 | One-minute accuracy cannot be read on the chosen dial. | 4 | 3 | 12 | Separate calculated accuracy from readable resolution; use large dials and five-minute markings.
R-005 | Frame flexibility overwhelms cam accuracy. | 2 | 4 | 8 | 20x40 perimeter/crossmembers and local 6 mm plates; measure deflection and shaft normality.
R-006 | Rack differential adds excessive play or friction. | 3 | 4 | 12 | Use quality-8 module-1 parts, dual linear rails, opposed flank springs, and module-first acceptance.
R-007 | Coaxial azimuth hands are difficult to fabricate and align. | 3 | 3 | 9 | Ground 8 mm inner shaft, 14/8.1 mm tube, replaceable bushings, wave-spring preload.
R-008 | Astronomical convention differs from published sunrise data. | 1 | 3 | 3 | Mitigated for P1: convention frozen and full year passes NREL SPA vs JPL DE421 validation; retain ideal-horizon warning.
R-009 | Atmospheric and terrain effects are mistaken for mechanism error. | 3 | 3 | 9 | State that the display represents a standardized ideal horizon.
R-010 | POM cams move after rough machining or clamping. | 3 | 4 | 12 | Stress-relieved stock, rough/stabilize 24 h, finish pilot/profile together, coupon approval before production.
R-013 | Incorrect bearing compensation or follower geometry corrupts the cam scale. | 2 | 5 | 10 | Source generates the inward normal offset for a 16 mm roller; automated scale, closure, pressure-angle, and mesh checks run on every verification.
R-014 | Vendor silently smooths or resamples the cam profile. | 2 | 5 | 10 | STEP/DXF are geometry masters, CSV is inspection reference, RFQ forbids smoothing and requires 16-station results.
R-015 | Bending or parallax at the large hands dominates reading error. | 3 | 3 | 9 | 5052 hands, 1.5-3 mm dial gap, guard clearance, and integrated optical/angle check.

ID | Risk | L | C | Priority | Initial response
R-016 | P1 test bypass leaves follower and preload behavior uncharacterized. | 4 | 4 | 16 | P2 coupon gate and separate cam/time/azimuth module tests are mandatory before integration.
R-011 | Annual automatic drive requires more torque than a clock movement supplies. | 4 | 3 | 12 | Keep early date input manual; characterize torque before choosing a drive.
R-012 | Uncontrolled scope shifts the project toward a wristwatch too early. | 3 | 5 | 15 | Treat the 36 by 24 inch demonstrator as the current product and wrist scale as a separate future project.

## First risk-reduction experiments

1. Print a constant-slope calibration cam and measure follower repeatability.
2. Print one fixed-latitude annual azimuth cam.
3. Print one fixed-latitude annual daylight-duration cam at several output scales.
4. Compare roller and sliding followers.
5. Measure frame and shaft deflection under the intended preload.
6. Test a reversible output transmission and quantify lost motion.

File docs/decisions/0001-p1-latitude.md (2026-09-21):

# Decision 0001: P1 Latitude

Status: Accepted  
Date: 2026-09-21

## Context

The first physical cam prototype needs a single fixed latitude. This permits the
cam profile, follower, mechanical scale, and fabrication process to be validated
before variable-latitude surface cams are introduced.

## Decision

P1 shall use a latitude of 42.1 degrees north.

## Alternatives considered

- A rounded mid-latitude default such as 40 degrees north
- A different fixed latitude selected only for convenient calculation
- Proceeding directly to a variable-latitude surface

## Consequences

- All P1 reference tables and cam profiles will be generated for `phi = +42.1
  degrees`.
- P1 parts and test reports must identify the latitude explicitly.
- Results at 42.1 degrees north validate the fixed-latitude implementation but do
  not by themselves validate the full -60 through +60 degree requirement.
- The variable-latitude P3 mechanism remains unchanged in scope.

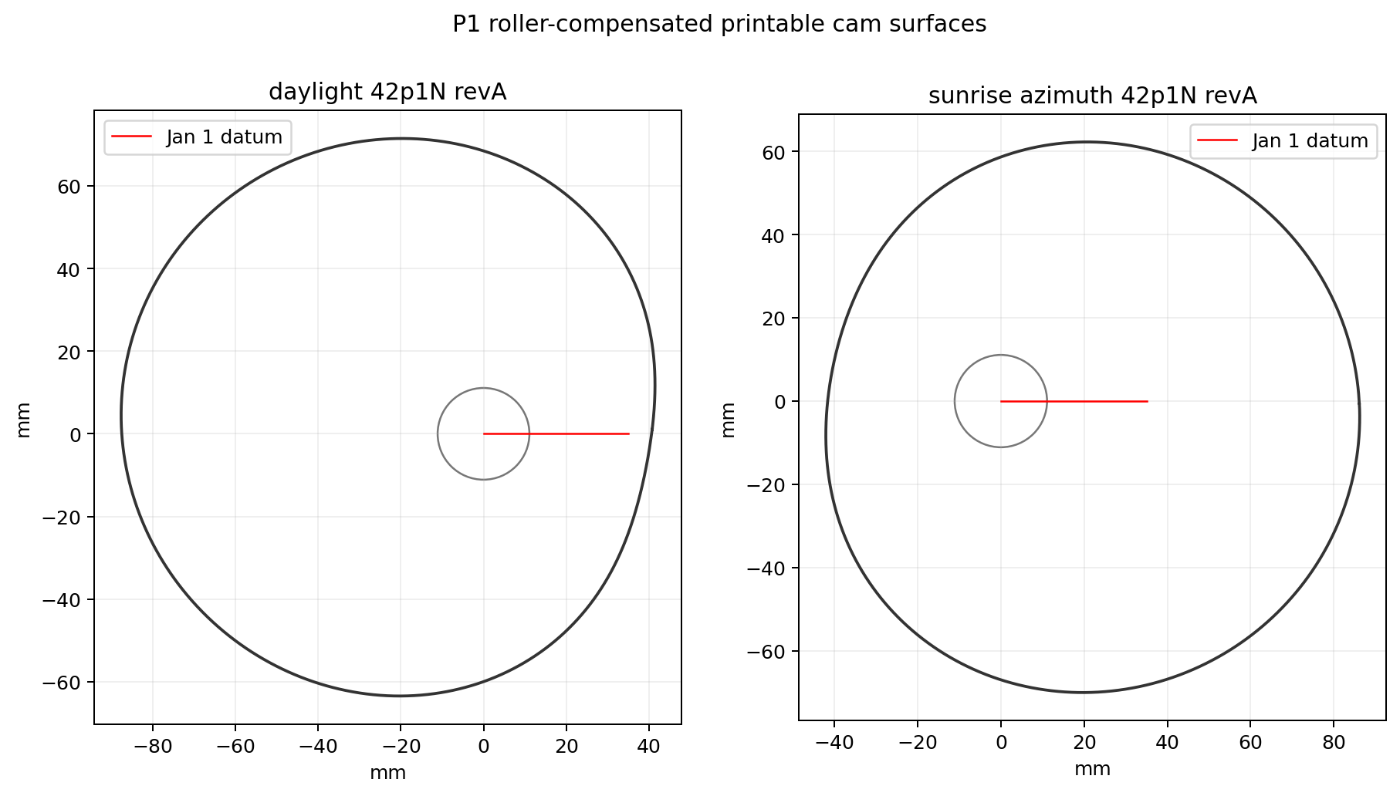
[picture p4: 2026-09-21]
artifacts/plots/p1_cam_profiles_42p1N.png

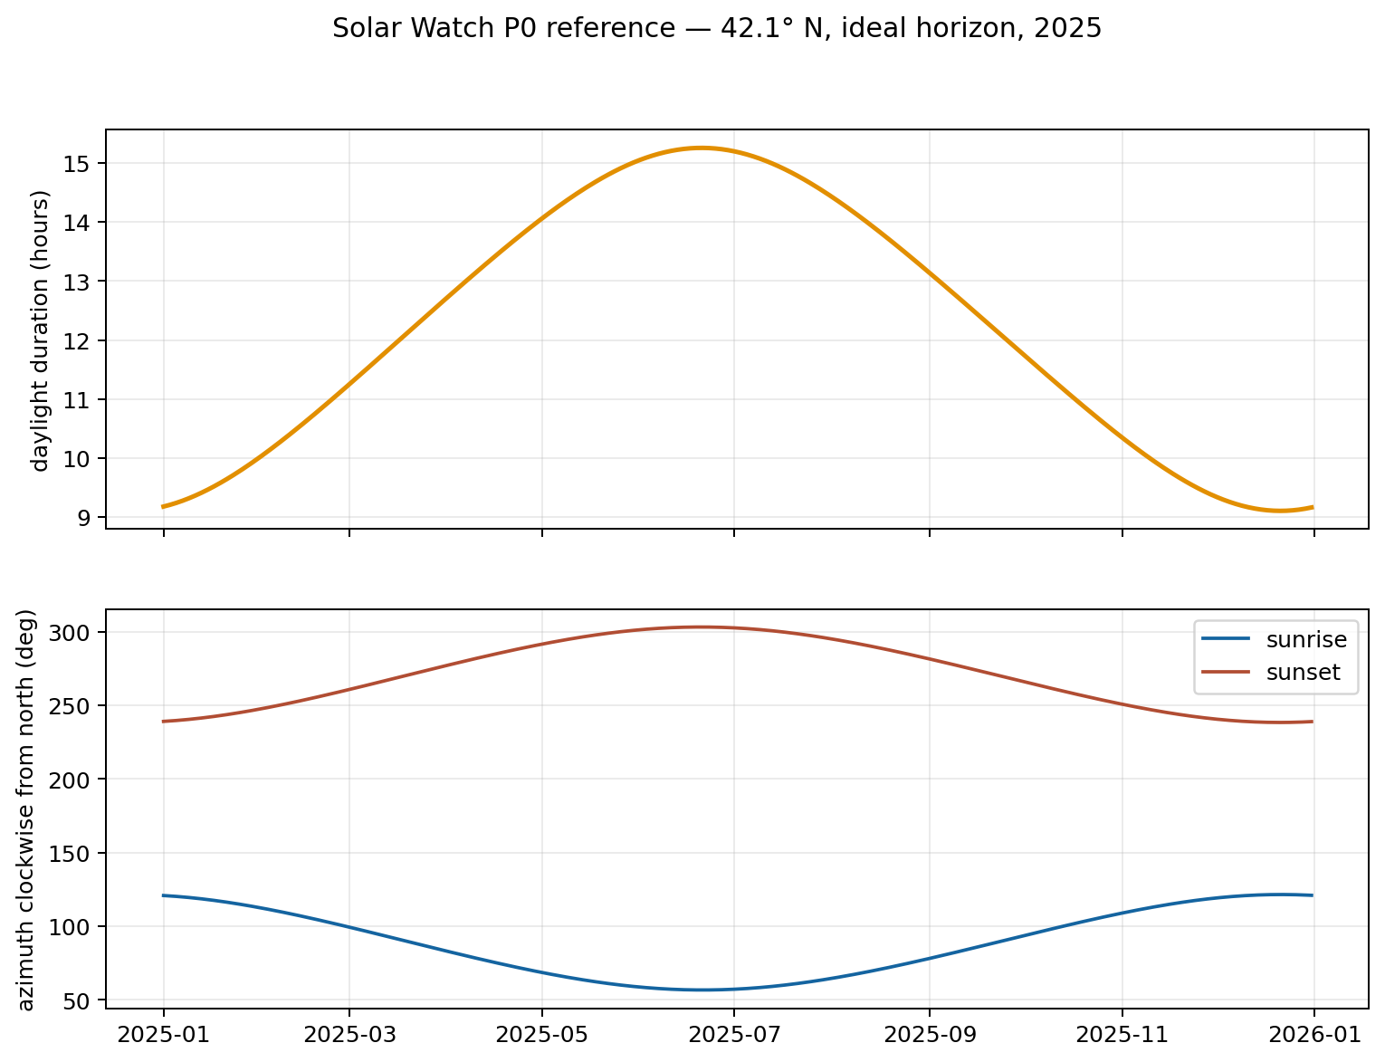
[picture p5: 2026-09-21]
artifacts/plots/p0_reference_42p1N_2025.png

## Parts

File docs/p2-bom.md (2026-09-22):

# P2 Bill of Materials

Status: Quotation BOM, Rev A
Currency and supplier are intentionally open until the manufacturing package is
reviewed. Quantities include one assembly unless a spare is stated.

## Custom CNC and cut parts

| Item | Qty | Description | Material / process | Master files |
|---|---:|---|---|---|
| P2-101 | 1 | Daylight-duration cam | 10 mm POM-C, 3-axis profile finish | STEP, DXF, CSV, PDF |
| P2-102 | 1 | Sunrise-azimuth cam | 10 mm POM-C, 3-axis profile finish | STEP, DXF, CSV, PDF |
| P2-103 | 2 | Cam hub | 6061-T6, turn/mill, clear anodize | STEP, DXF, PDF |
| P2-104 | 1 | Cam module plate | 6 mm 6061-T6, mill, clear anodize | STEP, DXF, PDF |
| P2-105 | 1 | Daylight span lever | 6 mm 6061-T6, mill, clear anodize | STEP, DXF, PDF |
| P2-106 | 1 | Azimuth span lever | 6 mm 6061-T6, mill, clear anodize | STEP, DXF, PDF |
| P2-107 | 1 | Time carrier plate | 6 mm 6061-T6, mill, clear anodize | STEP, DXF, PDF |
| P2-108 | 1 | Time module plate | 6 mm 6061-T6, mill, clear anodize | STEP, DXF, PDF |
| P2-109 | 1 | Azimuth module plate | 6 mm 6061-T6, mill, clear anodize | STEP, DXF, PDF |
| P2-110 | 1 | Sunrise time shaft | 303 stainless, turn/grind | STEP, PDF |
| P2-111 | 1 | Sunset output shaft | 303 stainless, turn/grind | STEP, PDF |
| P2-112 | 1 | Azimuth inner shaft | 303 stainless, turn/grind | STEP, PDF |
| P2-113 | 1 | Azimuth outer tube | 303 stainless, turn/grind | STEP, PDF |
| P2-115 | 1 | Removable guard | 4.5 mm clear polycarbonate, route | STEP, DXF, PDF |
| P2-116 | 2 | Functional time dial | 2.5 mm engraved/printed anodized aluminum | DXF, PDF |
| P2-117 | 1 | Functional azimuth dial | same as P2-116 | DXF, PDF |
| P2-118 | 2 | Time hand | 1.6 mm 5052-H32, laser/waterjet | STEP, DXF, PDF |
| P2-119 | 2 | Azimuth hand | 1.6 mm 5052-H32, laser/waterjet | STEP, DXF, PDF |
| P2-120 | 1 | Constant-radius cam runout coupon | 10 mm POM-C | STEP, DXF, PDF |
| P2-121 | 1 | 32 mm hub pilot fit coupon | 10 mm POM-C | STEP, DXF, PDF |
| P2-122 | 1 | 100 mm lever span gauge | 6 mm 6061-T6 | STEP, DXF, PDF |
| P2-123 | 1 | Keyed common cam/date shaft | 303 stainless, turn/mill/grind | STEP, DXF, PDF |
| P2-124 | 2 | Cam follower carriage | 6061-T6, mill, clear anodize | STEP, DXF, PDF |
| P2-125 | 3 | Rack clamp | 6061-T6, mill, clear anodize | STEP, DXF, PDF |
| P2-126 | 1 | Carrier output-rack bracket | 6061-T6, mill, clear anodize | STEP, DXF, PDF |
| P2-127 | 1 | Azimuth gear reducer bushing | 303 stainless, turn/grind | STEP, DXF, PDF |
| P2-128 | 1 | Date control shaft | 303 stainless, turn/grind | STEP, DXF, PDF |

P2-114 is a reference layout, not a separately manufactured part. Do not quote
STL files for production; they are inspection/preview derivatives only.

## Motion and bearing components

| Ref | Qty | Minimum specification | Notes |
|---|---:|---|---|
| B01 | 2 + 1 spare | Track roller, 16 OD x 5 bore x approximately 7 wide, sealed | cam followers |
| B02 | 8 | Flanged bearing, 8 ID, radial play C2 or standard | display shafts |
| B03 | 2 | Flanged bushing, 14 ID, dry-running polymer | outer azimuth tube |
| G01 | 3 | Module 1 rack, 20 degree PA, quality 8+, 120 mm usable teeth | two inputs plus carrier output |
| G02 | 1 | Module 1, 30 tooth spur pinion, 8 mm bore | sunrise input |
| G03 | 2 + 1 spare | Module 1, 15 tooth spur pinion, 8 mm bore | differential/output |
| G04 | 1 | Module 1, 80 tooth spur gear, 8 mm bore | sunrise azimuth |
| G05 | 1 set | 1:1 miter gears, 20 degree PA, 8 mm bores | azimuth reversal |
| L01 | 4 | 100 to 120 mm miniature profile rails with two carriages each | opposed racks/carrier |
| S01 | 2 | Extension spring, 1 to 2 N installed load, stainless | rack anti-backlash |
| S02 | 2 | Extension spring, 1 to 3 N over follower travel | cam preload |
| W01 | 4 | Wave spring washer for 8/14 mm coaxial stack | axial preload |
| D01 | 1 | HTD-5M timing belt, 15 wide, 760 pitch length | date input, 1:1 |
| D02 | 2 | HTD-5M pulley, 30 tooth, 15 belt width; 12 and 8 mm bores | cam shaft / control shaft |
| D03 | 1 | Smooth-back timing-belt idler with slotted mount | set belt tension, 10-20 N static |

Purchased gears may use imperial bores only if replaceable bushings preserve the
specified shaft journals and phase adjustments. Supplier part numbers are left
open for the vendor-selection stage.

## Shaft and bearing schedule

| Shaft | Journal / length | Supports | Mounted elements | Axial retention |
|---|---|---|---|---|
| P2-123 common cam/date | 12 h6 x 160, 4 mm keyway over 70 | two 12 mm flanged bearings, 110 span | two P2-103 hubs, D02 pulley | two 12 mm split collars |
| P2-128 date control | 8 h6 x 100 | two 8 mm flanged bearings, 55 span | date knob/hand, D02 pulley | shoulder plus 8 mm collar |
| P2-110 sunrise time | 8 h6 x 110 | two 8 mm flanged bearings, 65 span | G02 pinion, sunrise hand, input knob | shoulder plus 8 mm collar |
| P2-111 sunset output | 8 h6 x 95 | two 8 mm flanged bearings, 55 span | G03 output pinion, sunset hand | shoulder plus 8 mm collar |
| P2-112 azimuth inner | 8 h6 x 150 | two 8 mm flanged bearings, 90 span | G04 gear/bushing, sunrise hand | shoulder plus 8 mm collar |
| P2-113 azimuth tube | 14 h8 / 8.10 ID x 130 | two 14 mm bushings, 75 span | G05 driven miter, sunset hand | two wave washers and 14 mm collar |

## Fastener torque schedule

| Joint | Fastener | Dry assembly torque | Retention |
|---|---|---:|---|
| POM cam to hub | M5 class 8.8 with washer | 3 N m maximum | removable threadlocker |
| Aluminum module plates to T-slot | M6 class 8.8 | 8 N m | prevailing nut / T-nut |
| Rack clamps | M4 class 8.8 | 2.5 N m | removable threadlocker |
| Follower shoulder screws | M5 shoulder screw | 4 N m at thread | prevailing nut |
| Guard standoffs | M6, nylon washer | 3 N m | prevailing nut |

Verify that the POM remains flat after torque. Split collars and gear set screws
use their supplier torque, never the generic table.

## Frame and general hardware

| Ref | Qty | Specification |
|---|---:|---|
| F01 | 2 | 20 x 40 T-slot extrusion, 900 long |
| F02 | 4 | 20 x 40 T-slot extrusion, 569 long; two perimeter, two crossmembers |
| F03 | 8 | 20-series right-angle corner brackets with M5 fasteners |
| F04 | 12 | M6 adjustable standoffs, 35 to 55 long |
| H01 | 50 | M5 socket head screws, mixed 12/16/20 lengths, class 8.8 |
| H02 | 30 | M6 socket head screws and T-nuts, class 8.8 |
| H03 | 8 | M5 shoulder screws sized for B01 rollers |
| H04 | 8 | Split shaft collars, 8 mm bore; two with phase slots |
| H05 | 2 | Split shaft collars, 12 mm bore, keyed/date phase clamp |
| H06 | 12 | M5 all-metal prevailing torque jam nuts |
| H07 | 1 lot | 0.1/0.2/0.5 mm stainless shim washers |
| H08 | 1 lot | Medium-strength removable threadlocker and witness lacquer |

## Required inspection equipment (not consumed)

- 0 to 150 mm digital caliper, 0.01 mm display;
- 0 to 25 mm micrometer;
- dial indicator reading 0.01 mm with magnetic or rigid stand;
- 32 mm bore gauge or certified plug/ring masters;
- 4, 5, 6, 8, and 12 mm gauge pins or verified equivalents;
- 0 to 5 N spring scale;
- machinist square and surface plate or verified flat reference;
- protractor or optical angle encoder resolving 0.1 degree;
- printed test record from the included template.

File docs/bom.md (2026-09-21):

# P1 Bench Bill of Materials

Quantities cover one reusable test stand and both cams tested sequentially.
Equivalent metric hardware is acceptable if dimensions and substitutions are
recorded in the build log.

| Qty | Item | Specification / purpose |
|---:|---|---|
| 2 | 608-2RS or 608-ZZ bearing | 8 x 22 x 7 mm; one per cam |
| 1 | 625-2RS or 625-ZZ bearing | 5 x 16 x 5 mm roller follower |
| 1 | Precision or straight steel shaft | 8 mm diameter, at least 60 mm long |
| 2 | 8 mm shaft collars | axial location above and below test cam |
| 1 | M5 shoulder screw or smooth-shank bolt | 625 roller axle; avoid threaded contact in bearing bore |
| 1 | MGN12 rail and MGN12H carriage | 150 mm nominal radial follower guide |
| 1 | Light extension spring | approximately 1..3 N over the working stroke |
| 1 | Digital dial indicator | 0.01 mm resolution, at least 50 mm travel preferred |
| 1 | Adjustable indicator mount | rigid stand or baseboard bracket with ±5 mm zero travel |
| 1 | Flat baseboard | plywood/MDF/aluminum, about 300 x 300 x 12 mm |
| 1 | 608 shaft support | purchased flange/pillow block or rigid bracket retaining the 8 mm shaft |
| as needed | M3/M4/M5 fasteners, washers, inserts, nuts | rail, spring, guard, and indicator mounting |
| optional | 3 mm dowel or drill blank | Jan 1 datum-hole alignment pin |
| optional | clear guard | required before powered rotation; manual P1 tests may remain open with care |

## Printed material

Approximately 215 cm³ of solid model volume covers the two cams; slicer infill
and wall choices determine actual material use. The two coupons add about 110
cm³. PLA is the recommended first material because its stiffness and low warp
favor metrology. PETG is tougher and more temperature resistant but tends to
string and can produce a less crisp contact edge. Record brand, color, drying,
slicer, extrusion temperature, and measured shrinkage for every build.

No proprietary CAD, paid library, or system-wide software is required.

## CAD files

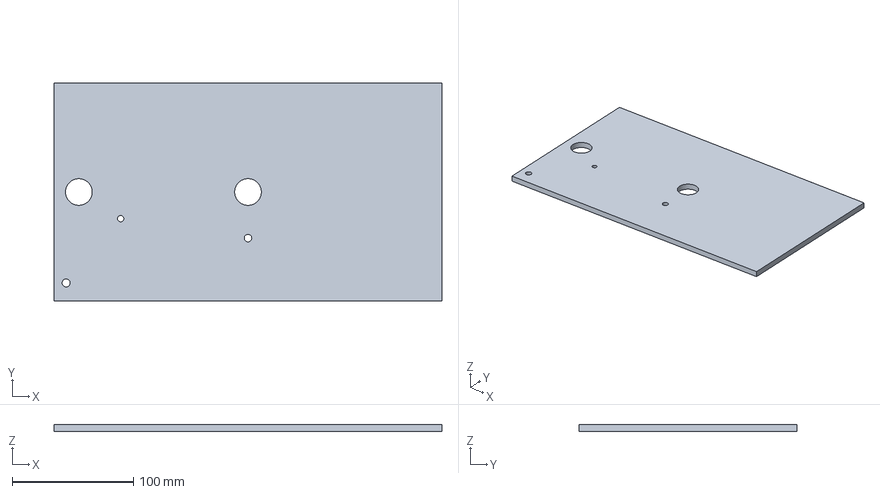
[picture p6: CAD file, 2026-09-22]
cnc/p2/P2-108_time_module_plate.step
320.0 x 180.0 x 6.00 mm

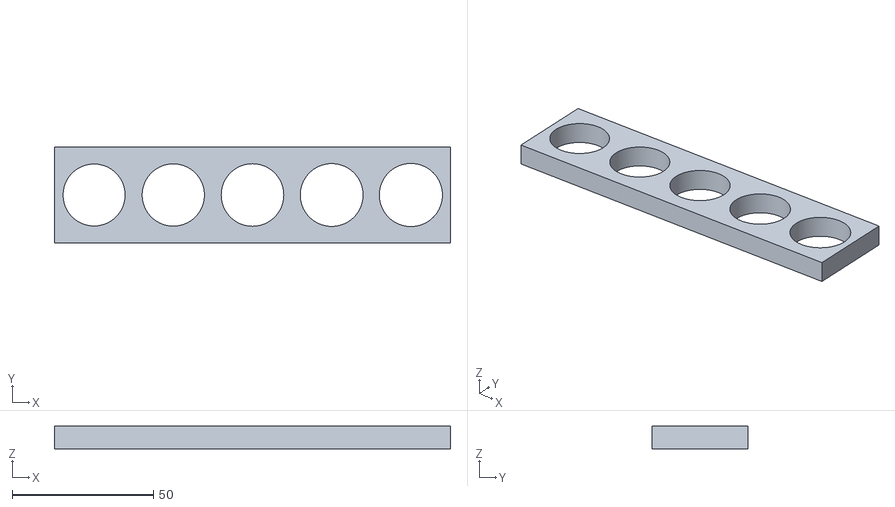
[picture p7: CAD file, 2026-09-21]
printables/p1/608_bearing_fit_21p9_to_22p3_revA.stl
140.0 x 34.0 x 8.00

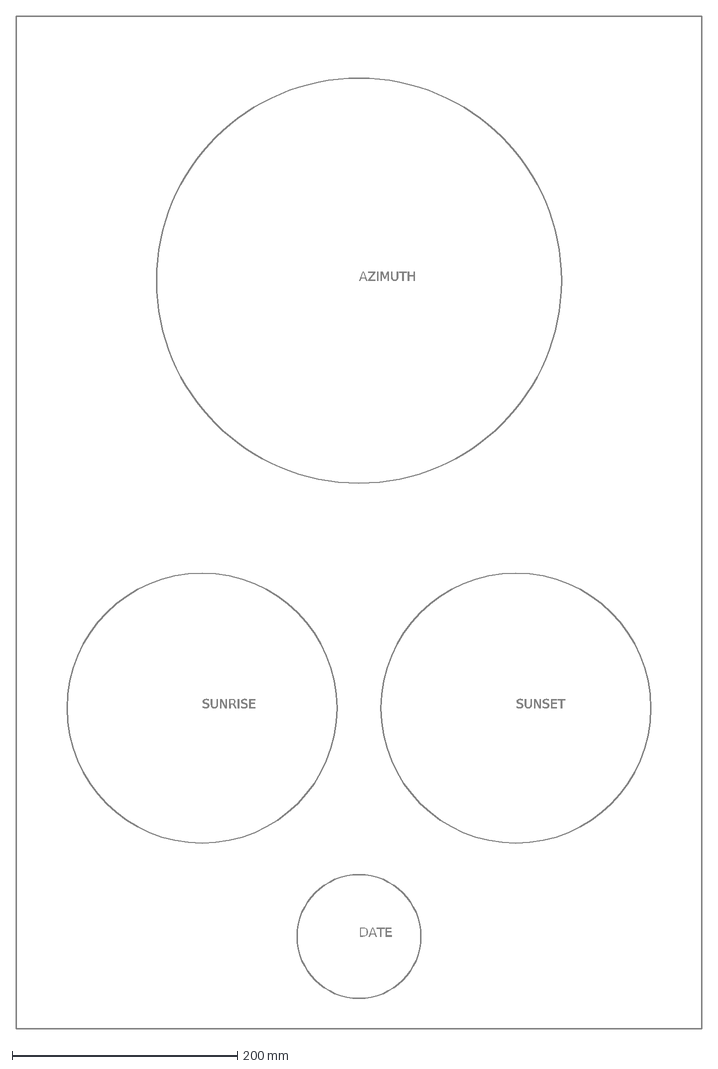
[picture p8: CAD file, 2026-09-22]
cnc/p2/P2-114_front_layout.dxf
AZIMUTH
SUNRISE
SUNSET
DATE

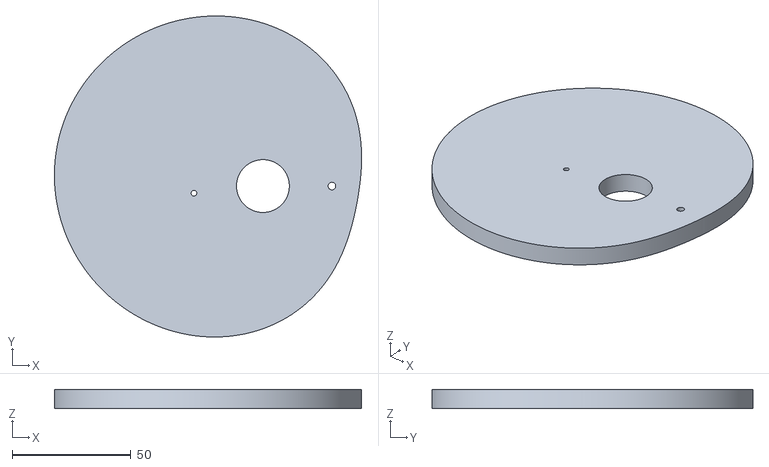
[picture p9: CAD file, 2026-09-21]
printables/p1/daylight_42p1N_revA.stl
129.2 x 135.0 x 8.00

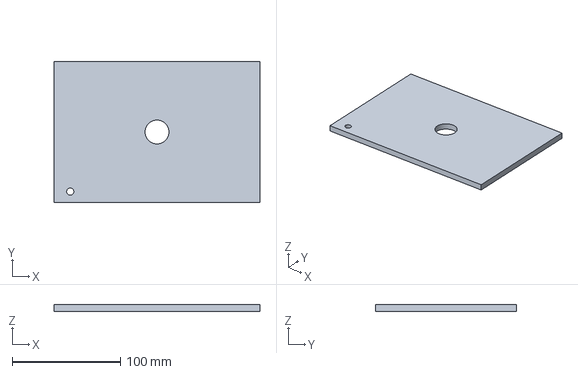
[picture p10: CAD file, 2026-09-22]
cnc/p2/P2-109_azimuth_module_plate.step
190.0 x 130.0 x 6.00 mm

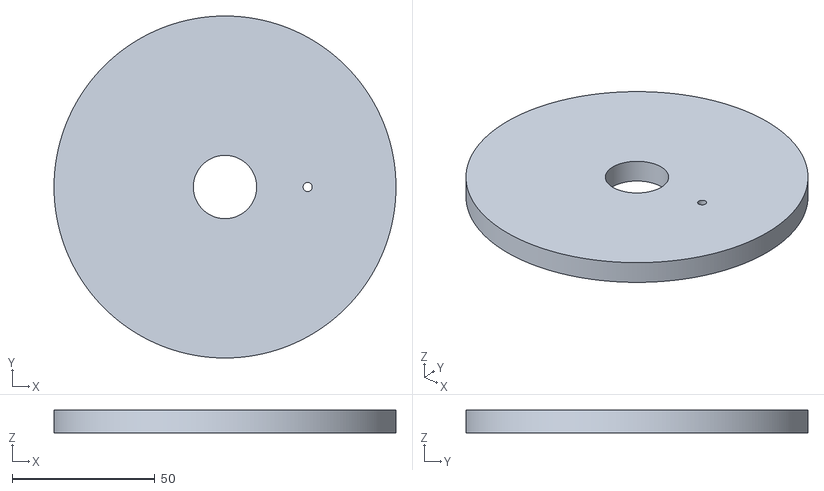
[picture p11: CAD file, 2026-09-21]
printables/p1/constant_radius_runout_revA.stl
120.0 x 120.0 x 8.00

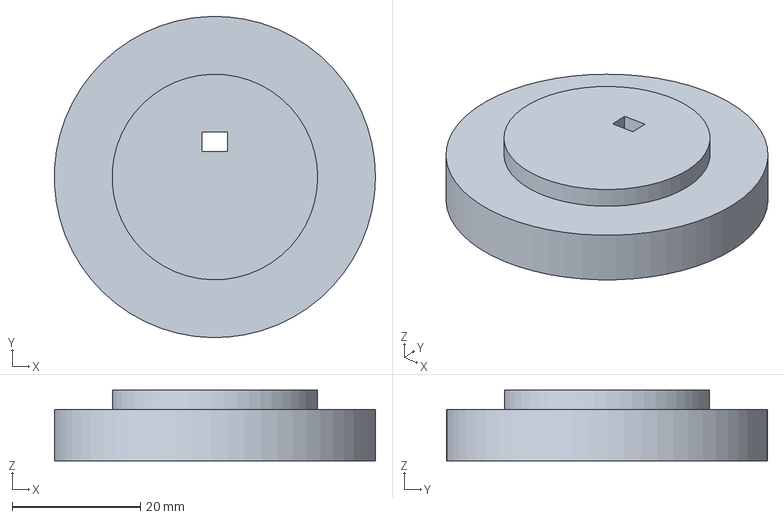
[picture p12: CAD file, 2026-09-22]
cnc/p2/P2-103_cam_hub.step
50.0 x 50.0 x 11.0 mm

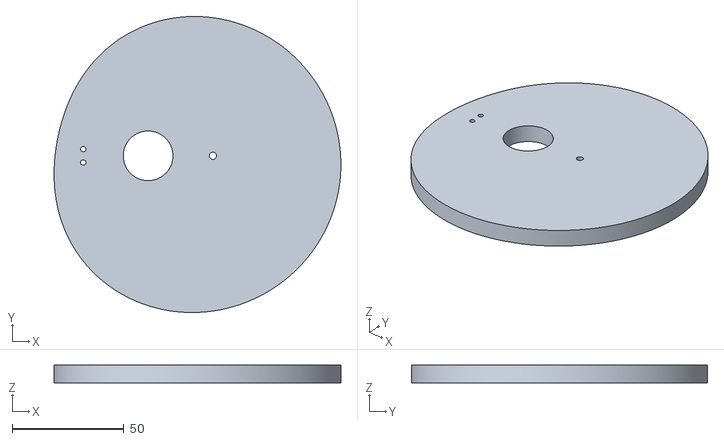
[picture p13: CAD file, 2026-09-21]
printables/p1/sunrise_azimuth_42p1N_revA.stl
128.3 x 132.4 x 8.00

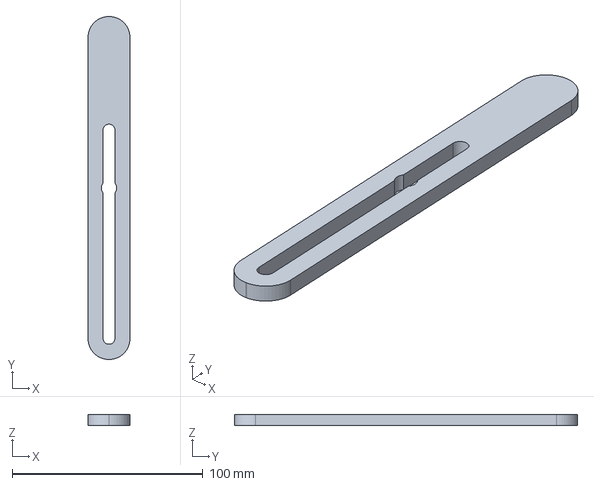
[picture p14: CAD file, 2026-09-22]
cnc/p2/P2-105_daylight_span_lever.step
22.0 x 180.0 x 6.00 mm

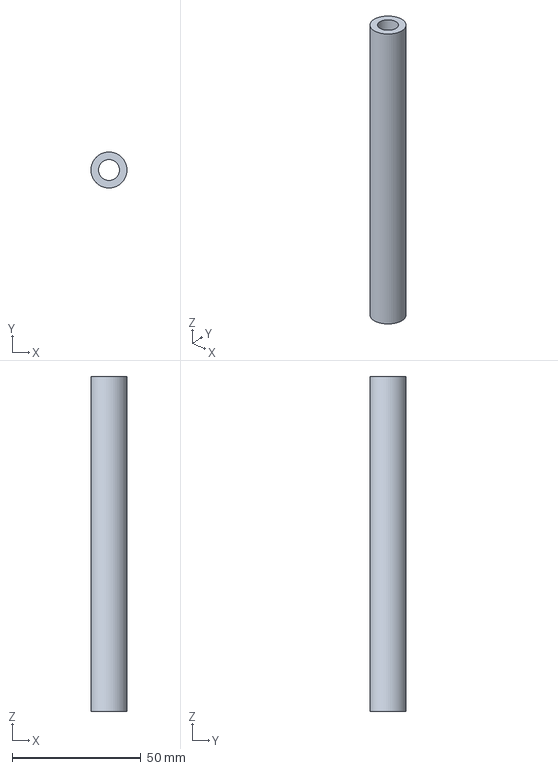
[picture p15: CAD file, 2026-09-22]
cnc/p2/P2-113_azimuth_outer_tube.step
14.0 x 14.0 x 130.0 mm

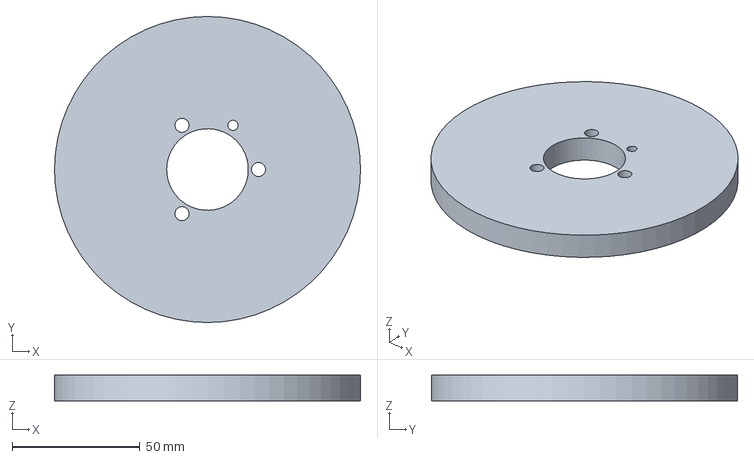
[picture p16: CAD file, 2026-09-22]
cnc/p2/P2-120_cam_runout_coupon.step
120.0 x 120.0 x 10.0 mm

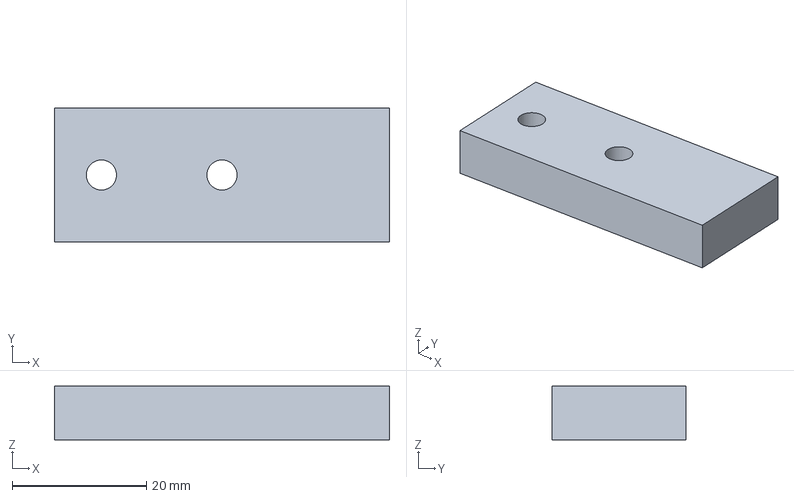
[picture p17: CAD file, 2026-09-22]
cnc/p2/P2-125_rack_clamp.step
50.0 x 20.0 x 8.00 mm

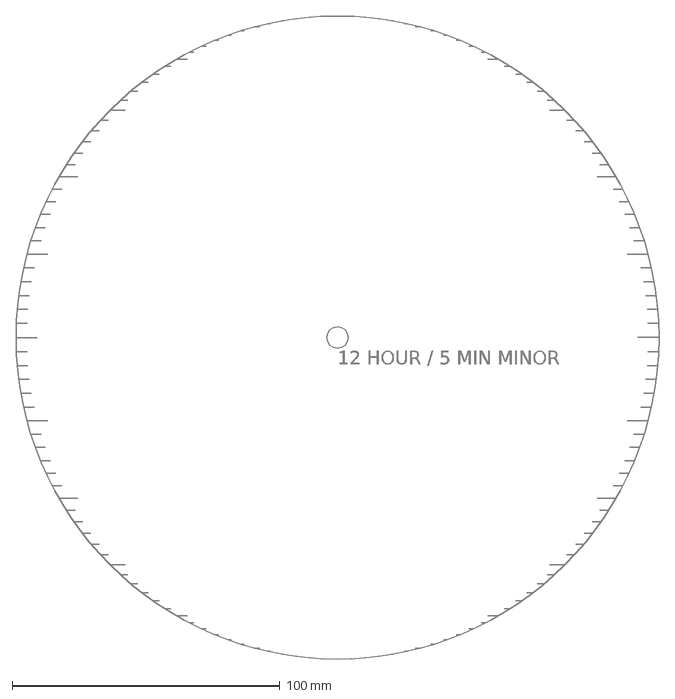
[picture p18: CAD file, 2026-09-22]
cnc/p2/P2-116_time_dial.dxf
12 HOUR / 5 MIN MINOR

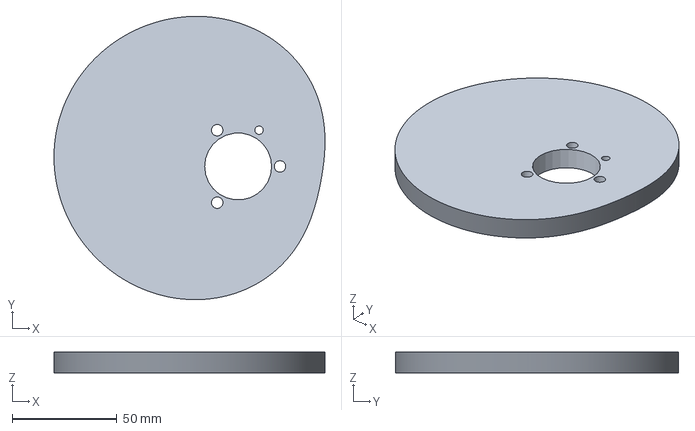
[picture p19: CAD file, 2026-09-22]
cnc/p2/P2-101_daylight_42p1N_p2_revA.step
129.5 x 135.4 x 10.0 mm

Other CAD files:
cnc/p2/P2-104_cam_module_plate.step
cnc/p2/P2-102_sunrise_azimuth_42p1N_p2_revA.step
cnc/p2/P2-127_azimuth_gear_bushing.step
cnc/p2/P2-122_lever_span_gauge.step
cnc/p2/P2-101_daylight_42p1N_p2_revA.dxf
cnc/p2/P2-101_daylight_42p1N_p2_revA.stl
cnc/p2/P2-102_sunrise_azimuth_42p1N_p2_revA.dxf
cnc/p2/P2-102_sunrise_azimuth_42p1N_p2_revA.stl
cnc/p2/P2-103_cam_hub.dxf
cnc/p2/P2-103_cam_hub.stl
cnc/p2/P2-104_cam_module_plate.dxf
cnc/p2/P2-104_cam_module_plate.stl
cnc/p2/P2-105_daylight_span_lever.dxf
cnc/p2/P2-105_daylight_span_lever.stl
cnc/p2/P2-106_azimuth_span_lever.dxf
cnc/p2/P2-106_azimuth_span_lever.step
cnc/p2/P2-106_azimuth_span_lever.stl
cnc/p2/P2-107_time_carrier_plate.dxf
cnc/p2/P2-107_time_carrier_plate.step
cnc/p2/P2-107_time_carrier_plate.stl
cnc/p2/P2-108_time_module_plate.dxf
cnc/p2/P2-108_time_module_plate.stl
cnc/p2/P2-109_azimuth_module_plate.dxf
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

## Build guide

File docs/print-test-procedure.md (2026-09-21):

# P1 Print, Calibration, and Test Procedure

## 1. Create the software environment

From a clean checkout in PowerShell:

```powershell
.\scripts\bootstrap.ps1
.\scripts\verify.ps1
```

The scripts create and use `.venv` inside the project. They do not install
system-wide packages. `verify.ps1` runs tests, regenerates all derived files,
and fails if regeneration changes a committed artifact.

To independently refresh JPL data (network required only on the first run):

```powershell
.\.venv\Scripts\solar-watch.exe validate-ephemeris --root . --cache .cache/skyfield
.\scripts\regenerate.ps1
```

## 2. Record the build

Copy `docs/templates/p1-build-record.md` and assign an ID such as
`P1-2026-001`. Record printer, build volume, nozzle, material, layer height,
slicer/version, scaling, temperatures, wall count, infill, and every part
filename/hash. Do not apply slicer XY scaling unless the coupon result justifies
and records it.

## 3. Print coupons first

1. Print `608_bearing_fit_21p9_to_22p3_revA.stl` flat, no support. From left to
   right with the long dimension horizontal, the holes are 21.9 through 22.3 mm.
2. Allow the coupon and bearing to reach room temperature. Select the smallest
   hole into which the bearing seats fully without hammering, cracking, or
   visible ovalization, yet does not rock.
3. If 22.2 mm is not selected, edit the `bearing_bore_mm` default in
   `src/solar_watch/cam.py`, increment the part revision, regenerate, and repeat
   software verification. Do not scale only the bore in the slicer.
4. Print `constant_radius_runout_revA.stl`, install its bearing, shaft, roller,
   rail, indicator, and spring. Rotate it manually through 360 degrees.
5. Record total indicated runout clockwise and counter-clockwise. Investigate
   values above 0.10 mm before committing to full cams.

## 4. Slice and print cams

Recommended starting point for a 0.4 mm nozzle:

- PLA, flat on the marked face or the slicer's smoothest plate-facing side;
- 0.16 or 0.20 mm layers;
- at least four walls/perimeters and five top/bottom layers;
- 30..40% gyroid or grid infill;
- no support;
- no global XY scale compensation;
- seam placed at the Jan 1 ray where it can be identified and measured;
- elephant-foot compensation established by the fit coupon; and
- brim only if needed, kept off the finished contact surface after removal.

Print one cam at a time. Do not place a cam on edge. Let it cool on the plate.
Deburr without rounding the profile. If sanding is necessary, use a rigid block
parallel to the cam axis, preserve the bearing and datum features, and record
the process.

## 5. Assemble the measurement rig

1. Fix the 8 mm shaft perpendicular to a flat baseboard.
2. Fit the cam's 608 bearing and retain it axially with washers/collars without
   side-loading the bearing.
3. Align the MGN12 rail so its centerline intersects the shaft axis within
   ±0.5 mm.
4. Mount the 625 roller with its axis parallel to the cam shaft. Ensure only the
   bearing outer race contacts the cam.
5. Attach the 1..3 N extension spring so it pulls the carriage toward the shaft
   throughout the complete stroke.
6. Align the indicator with carriage motion. Exercise the system several times
   and confirm the follower never lifts or binds.

## 6. Establish datum and calibration

1. Put a 3 mm alignment pin through the Jan 1 datum hole and align the hole with
   the follower centerline. Remove the pin before rotating.
2. Set the date by rotating the marked face clockwise from Jan 1 at
   `0.986301 deg/day`.
3. Zero the indicator at Jan 1 and record its absolute reading if available.
4. Measure the winter and summer extrema. Fit measured displacement `m` to the
   nominal pitch displacement `p` with `p = a*m + b`; retain `a` and `b` in the
   build record. This is the permitted span/zero calibration.
5. Do not change the generated cam profile or manually distort selected dates.

## 7. Annual verification

Use `data/p1_test_points_42p1N_2025.csv`. At each date:

1. Approach clockwise, settle without tapping, and record the indicator.
2. Pass the date, approach counter-clockwise, and record again.
3. Repeat the clockwise approach for repeatability.
4. Convert calibrated displacement with the formulas in
   `docs/p1-cam-package.md` and calculate absolute error against the reference.
5. Record backlash/hysteresis separately from mean absolute calibration error.

Minimum acceptance evidence for each cam:

- all prescribed dates measured;
- no follower lift, binding, or end-of-travel contact;
- runout, clockwise error, counter-clockwise error, repeatability, and surface
  finish recorded;
- azimuth absolute error ≤1 degree; and
- daylight results reported against the one-minute design target, without
  claiming success if the physical data exceed it.

Stop after the P1 report. Do not add a differential, dial artwork, variable
latitude, or P2 integration to solve a P1 measurement problem.

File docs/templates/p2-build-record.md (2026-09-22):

# P2 Build and Acceptance Record

- Assembly serial:
- Drawing revision: A
- Manifest SHA-256:
- Builder / date:
- Machining supplier / lot:
- POM-C certificate:
- Aluminum certificate:
- Ambient temperature:

## Coupon results

| Feature | Nominal | Measured | Pass |
|---|---:|---:|---|
| Pilot coupon hole 1 | 31.98 | | |
| Pilot coupon hole 2 | 32.00 | | |
| Pilot coupon hole 3 | 32.02 | | |
| Pilot coupon hole 4 | 32.04 | | |
| Selected hub diameter | 32 h6 | | |
| Runout coupon TIR | <= 0.05 | | |
| Span gauge centers | 100.00 +/- 0.03 | | |

## Module calibration

| Item | Nominal | As-built | Locked / witnessed |
|---|---:|---:|---|
| Daylight span ratio | 1.000000 | | |
| Azimuth span ratio | 1.000000 | | |
| Follower preload daylight | 1-3 N | | |
| Follower preload azimuth | 1-3 N | | |
| Rack preload | 1-2 N | | |
| Date belt static tension | 10-20 N | | |
| Date phase hysteresis | <=0.20 deg | | |
| Date input torque | <=250 N mm | | |
| Sunrise input torque | <=75 N mm | | |

## Integrated sweep

Attach CSV with date, approach direction, sunrise setting, expected/observed
sunset, expected/observed sunrise azimuth, expected/observed sunset azimuth,
errors, temperature, and notes.

- Maximum time error:
- Maximum azimuth error:
- Maximum repeatability error:
- Maximum hysteresis:
- Maximum mirror error:
- Envelope measured:
- Guard clearance minimum:
- Frame midspan deflection at 10 N:
- Shaft runout maximum:
- Final disposition:
- Deviations and corrective action:

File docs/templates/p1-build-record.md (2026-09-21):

# P1 Build Record

- Build ID:
- Date:
- Operator:
- Commit:
- Part filename(s) and SHA-256:
- Printer / build volume:
- Nozzle:
- Material / brand / color / drying:
- Slicer / version:
- Layer height / line width:
- Walls / top / bottom / infill:
- Temperatures / cooling:
- Seam / elephant-foot / scaling settings:
- Selected 608 coupon bore:
- Runout CW / CCW:
- Spring and estimated preload:
- Indicator model / range / resolution:
- Zero coefficient `b` / span coefficient `a`:
- Test data attachment:
- Deviations and observations:
- Pass/fail statement:

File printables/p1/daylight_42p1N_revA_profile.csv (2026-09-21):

day_coordinate | cam_angle_deg | pitch_radius_mm | surface_x_mm | surface_y_mm | surface_radius_mm | pressure_angle_deg | pitch_curvature_radius_mm
0.000000000 | 0.000000000 | 48.733380212 | 40.808371228 | 1.092809499 | 40.823000806 | 7.851218999 | 13.289358415
0.126736111 | 0.125000000 | 48.747744671 | 40.814642843 | 1.139664125 | 40.830551119 | 7.546293909 | 15.479376793
0.253472222 | 0.250000000 | 48.761599292 | 40.821741437 | 1.195629170 | 40.839247092 | 7.307098066 | 18.549689536
0.380208333 | 0.375000000 | 48.775068435 | 40.829620188 | 1.260745586 | 40.849080334 | 7.133774219 | 23.155447473
0.506944444 | 0.500000000 | 48.788276458 | 40.838262053 | 1.335040874 | 40.860078091 | 7.026401393 | 30.818049989
0.633680556 | 0.625000000 | 48.801347722 | 40.847680309 | 1.418530554 | 40.872303771 | 6.984999962 | 46.062388985
0.760416667 | 0.750000000 | 48.814406585 | 40.857918868 | 1.511219145 | 40.885857182 | 7.009534239 | 91.045839910
0.887152778 | 0.875000000 | 48.827577408 | 40.869052380 | 1.613100627 | 40.900874514 | 7.099912569 | 3525.543785055
1.013888889 | 1.000000000 | 48.840984516 | 40.881178473 | 1.724088728 | 40.917517463 | 7.255483001 | inf
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

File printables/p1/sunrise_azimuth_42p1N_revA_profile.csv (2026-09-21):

day_coordinate | cam_angle_deg | pitch_radius_mm | surface_x_mm | surface_y_mm | surface_radius_mm | pressure_angle_deg | pitch_curvature_radius_mm
0.000000000 | 0.000000000 | 94.102881407 | 86.117399431 | -0.481744347 | 86.118746870 | 3.452328361 | inf
0.126736111 | 0.125000000 | 94.090741305 | 86.104983992 | -0.275617279 | 86.105425108 | 3.321207565 | 1417.771178236
0.253472222 | 0.250000000 | 94.079022186 | 86.092784823 | -0.073566478 | 86.092816254 | 3.218960160 | 316.614795337
0.380208333 | 0.375000000 | 94.067619997 | 86.080703121 | 0.124404700 | 86.080793017 | 3.145620202 | 178.094256268
0.506944444 | 0.500000000 | 94.056430683 | 86.068646129 | 0.318293311 | 86.069234673 | 3.101215021 | 123.848948762
0.633680556 | 0.625000000 | 94.045350190 | 86.056527164 | 0.508096731 | 86.058027108 | 3.085766090 | 94.914630717
0.760416667 | 0.750000000 | 94.034274464 | 86.044265633 | 0.693812611 | 86.047062845 | 3.099289668 | 76.930860985
0.887152778 | 0.875000000 | 94.023099449 | 86.031787045 | 0.875438874 | 86.036241057 | 3.141797232 | 64.672717203
1.013888889 | 1.000000000 | 94.011721122 | 86.019020774 | 1.053004523 | 86.025465726 | 3.213074785 | 56.869741557
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

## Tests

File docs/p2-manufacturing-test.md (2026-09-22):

# P2 Manufacturing, Assembly, Calibration, and Test Procedure

Status: Release candidate, Rev A
This procedure is mandatory evidence for physical acceptance. A clean software
verification does not replace it.

## 1. Incoming file and material control

1. Confirm the quotation references Rev A, millimetres, the PDF drawings, STEP
   models, DXFs, and the matching `SHA256SUMS.txt`.
2. Reject a quote that proposes machining from STL.
3. Obtain material certifications for POM-C, 6061-T6, and 303 stainless.
4. Require the machinist to identify any conflict between PDF notes and CAD
   before cutting. PDF controls tolerances/finish; STEP/DXF controls form.

## 2. Coupon gate before production cams

1. Machine P2-121 from the same POM-C stock and process intended for the cams.
2. Measure all four marked bores: 31.98, 32.00, 32.02, and 32.04 nominal.
3. Fit the first P2-103 hub. Select the process offset that produces free hand
   assembly with no detectable rocking; record the actual bore and hub diameter.
4. Machine P2-120 and mount it on that hub with the production screws and dowel.
5. Indicate the 120 mm diameter while rotating the date shaft. Total indicated
   runout must be 0.05 mm or less. If it fails, isolate shaft, hub-pilot, and
   profile contributions before authorizing production cams.
6. Inspect P2-122 hole-center distance. It must be 100.00 plus/minus 0.03. Use it
   to validate the setup used for lever slot and pivot locations.

## 3. Custom-part inspection

1. Verify manifest hashes and count every part against the BOM.
2. Inspect controlled interfaces I-01 through I-14 from the ICD.
3. On each cam, record thickness at four quadrants, pilot size, datum-hole
   position, face parallelism, and profile deviation at 16 specified dates.
4. Indicate each shaft journal and hand seat. Total indicated runout must not
   exceed 0.025 mm.
5. Roll-test purchased racks/gears over their full used travel. Reject tight
   spots, burrs, visible tooth damage, or backlash above 0.10 mm at the pitch
   line before spring preload.

## 4. Cam module assembly

1. Install bearings and the 12 mm date shaft without cams. Confirm free rotation
   and no more than 0.025 mm radial shaft runout at each hub position.
2. Install P2-128, the two 30-tooth pulleys, 760 mm belt, and idler. Set static
   belt tension to 10-20 N and verify 1:1 phase over two control revolutions.
3. Install hubs, dowels, and cams with both January 1 rays aligned. Tighten M5
   cam screws progressively to 3 N m; POM must not dish or gap from the hub.
4. Install each 16 mm track roller and set 1 to 3 N follower preload. Sweep one
   full revolution by hand. Contact must be continuous and torque smooth.
5. Record roller-center displacement at the 16 dates in
   `data/p1_test_points_42p1N_2025.csv`. Correct for the P2 hub datum only; do
   not alter the generated profile.

Acceptance: daylight displacement error at most 0.10 mm, azimuth displacement
error at most 0.20 mm, repeatability 0.05 mm, and clockwise/counter-clockwise
hysteresis 0.10 mm or less. Date control-to-cam phase hysteresis shall be no more
than 0.20 degree. These module limits reserve error for transmissions.

## 5. Time module assembly and calibration

1. Install both opposed racks, rails, 15-tooth differential pinion, carrier,
   30-tooth sunrise pinion, and 15-tooth output pinion dry.
2. Align pitch lines within 0.05 mm and install 1 to 2 N anti-backlash springs.
3. Use P2-122 to set the daylight lever nominal ratio to 1.000000. Leave jam
   nuts finger-tight.
4. With daylight follower at its 545-minute datum, set the sunset phase collar
   to the same indicated time as sunrise plus 9 h 05 min modulo 12 hours.
5. At winter and summer daylight extrema, adjust lever span equally about the
   datum until both errors have equal magnitude and opposite sign. Lock nuts,
   apply witness lacquer, and repeat.
6. Exercise sunrise in 15-minute steps through 12 hours at both daylight
   extrema. Compare sunset to `(sunrise + daylight) mod 720 minutes`.

Acceptance: maximum sunset indication error 1.0 minute, repeatability 0.5 minute,
and direction-dependent hysteresis 0.5 minute.

## 6. Azimuth module assembly and calibration

1. Install the 80-tooth pinion, coaxial shaft/tube, 1:1 miter reverser, wave
   washers, and hands. Preload without perceptible axial play or binding.
2. Set the azimuth lever nominal ratio to 1.000000 using P2-122.
3. At the spring-equinox reference, set the sunrise hand to the reference table
   and set sunset equal and opposite about north-south.
4. At both solstices, trim lever span for equal and opposite sunrise errors.
5. Sweep all 16 test dates in both directions, reading both hands.

Acceptance: each hand within 1.0 degree of the reference, repeatability 0.5
degree, hysteresis 0.5 degree, and mirror error 1.0 degree.

## 7. Frame, dial, and guard assembly

1. Square the extrusion frame so diagonal lengths differ by no more than 1 mm.
2. Mount module plates at the ICD Z stations. Verify shafts are normal to the
   dial plane within 0.1 degree.
3. Install functional dials at the P2-114 centers. Verify every hand clears its
   dial by 1.5 to 3 mm and adjacent hands by at least 1 mm.
4. Install the guard. Confirm at least 8 mm clearance to every moving part and
   that routine zero/span fasteners remain reachable after removing only the
   guard—not another calibrated module.
5. Measure the completed assembly. It must not exceed 609 x 900 x 200.

## 8. Integrated acceptance sweep

Test the 16 prescribed dates with sunrise settings of 04:00, 06:00, 08:00, and
10:00. Approach every setting clockwise first, then counter-clockwise. Record:

- measured daylight follower displacement;
- sunrise and sunset time indication;
- sunrise and sunset azimuth indication;
- setting direction, ambient temperature, and anomalies.

Pass only when all 64 states meet the time and azimuth acceptance limits and no
follower loses contact. Photograph the mechanism at both solstices and archive
the completed build record, raw data, deviations, and disposition.

## 9. Stop conditions

Stop and investigate rather than re-machining a generated profile when runout
exceeds the coupon limit, the follower unloads, a rack binds, the guard is
contacted, calibration requires more than the documented adjustment range, or
results depend on approach direction beyond the hysteresis limit.

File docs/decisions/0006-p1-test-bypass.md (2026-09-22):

# Decision 0006: Proceed to P2 Without Physical P1 Testing

Status: Accepted by user

Date: 2026-09-21

## Context

The P1 software, reference data, and printable cam package were completed, but
the coupons and cams were not physically manufactured or measured before the
user chose to proceed directly to a CNC-oriented P2 design.

## Decision

Proceed with P2 detailed design while treating all fabrication, runout,
follower preload, friction, hysteresis, structural-deflection, and wear claims
as unverified until P2 module testing. CNC capability may reduce manufacturing
error but does not replace mechanism testing.

## Consequences

- P2 includes module-level inspection and bench-test procedures before final
  display assembly.
- Error budgets identify assumed versus digitally proven contributions.
- The design must retain adjustment margin instead of relying on nominal CAD.
- No document may claim physical achievement of `ACC-003` through `ACC-006`.

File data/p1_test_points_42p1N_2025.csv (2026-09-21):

date | day_of_year | cam_angle_deg | daylight_min | daylight_pitch_radius_mm | sunrise_azimuth_deg | azimuth_pitch_radius_mm
2025-01-01 | 1 | 0.000000000 | 550.641386243 | 48.733380212 | 120.861259153 | 94.102881407
2025-02-01 | 32 | 30.575342466 | 601.931747946 | 55.401127233 | 112.400327013 | 88.180228909
2025-03-01 | 60 | 58.191780822 | 675.220398251 | 64.928651773 | 99.330516378 | 79.031361465
2025-03-20 | 79 | 76.931506849 | 729.173295917 | 71.942528469 | 89.315665055 | 72.020965539
2025-04-01 | 91 | 88.767123288 | 763.295683000 | 76.378438790 | 82.976400838 | 67.583480587
2025-05-01 | 121 | 118.356164384 | 843.539122717 | 86.810085953 | 68.567898357 | 57.497528850
2025-06-01 | 152 | 148.931506849 | 902.974527429 | 94.536688566 | 58.676033265 | 50.573223286
2025-06-21 | 172 | 168.657534247 | 915.289799740 | 96.137673966 | 56.685009707 | 49.179506795
2025-07-01 | 182 | 178.520547945 | 911.769781896 | 95.680071646 | 57.199684776 | 49.539779343
2025-08-01 | 213 | 209.095890411 | 865.346135001 | 89.644997550 | 64.629203455 | 54.740442418
2025-09-01 | 244 | 239.671232877 | 787.897125343 | 79.576626295 | 78.181737191 | 64.227216034
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

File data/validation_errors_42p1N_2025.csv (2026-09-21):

date | sunrise_error_min | sunset_error_min | daylight_error_min | sunrise_azimuth_error_deg | sunset_azimuth_error_deg
2025-01-01 | 0.001163683 | 0.001358517 | 0.000194843 | 0.000005137 | 0.000065777
2025-01-02 | 0.001161800 | 0.001374767 | 0.000212971 | 0.000001544 | 0.000068169
2025-01-03 | 0.001164800 | 0.001392583 | 0.000227784 | -0.000000914 | 0.000070511
2025-01-04 | 0.001165883 | 0.001399200 | 0.000233313 | -0.000002805 | 0.000071594
2025-01-05 | 0.001161550 | 0.001396883 | 0.000235328 | -0.000004019 | 0.000072254
2025-01-06 | 0.001151983 | 0.001383650 | 0.000231672 | -0.000004294 | 0.000072287
2025-01-07 | 0.001130467 | 0.001363083 | 0.000232609 | -0.000004847 | 0.000072192
2025-01-08 | 0.001108467 | 0.001338017 | 0.000229542 | -0.000004668 | 0.000072073
2025-01-09 | 0.001084167 | 0.001311850 | 0.000227688 | -0.000004694 | 0.000071939
2025-01-10 | 0.001055633 | 0.001296917 | 0.000241276 | -0.000006306 | 0.000073274
2025-01-11 | 0.001035700 | 0.001289550 | 0.000253848 | -0.000008009 | 0.000075296
2025-01-12 | 0.001019267 | 0.001293067 | 0.000273786 | -0.000010847 | 0.000078138
2025-01-13 | 0.001007500 | 0.001307017 | 0.000299513 | -0.000014871 | 0.000081721
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

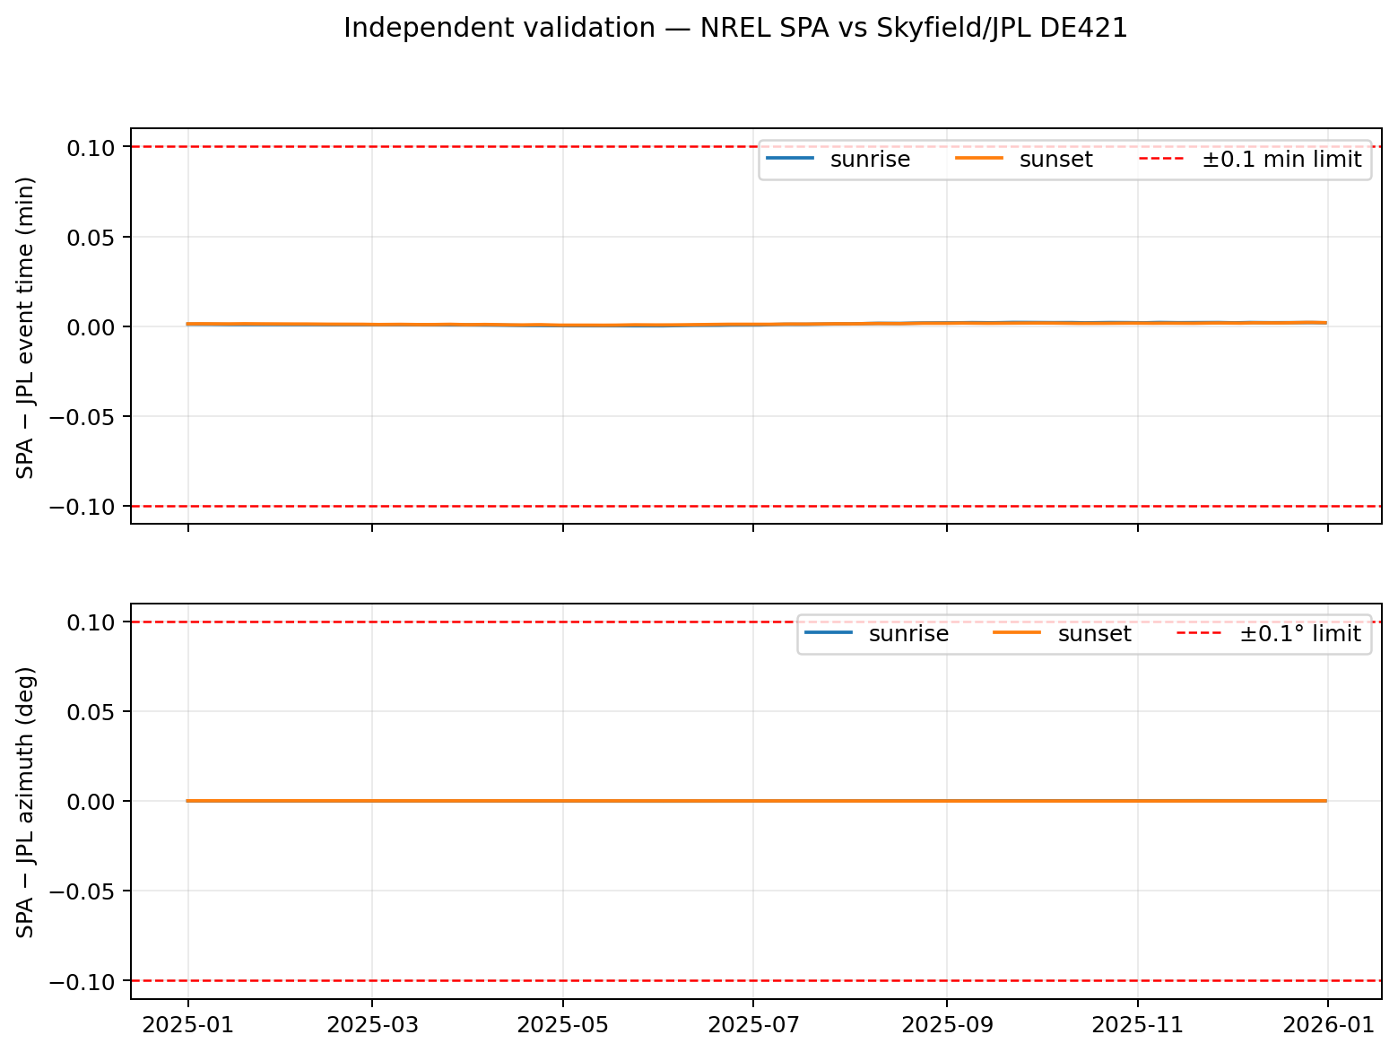
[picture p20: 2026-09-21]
artifacts/plots/p0_validation_errors_42p1N_2025.png

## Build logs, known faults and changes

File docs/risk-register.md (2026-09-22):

# Risk Register

Status: P2 Rev A
Date: 2026-09-22

Scores use likelihood and consequence from 1 (low) through 5 (high). Priority is
their product and is provisional until physical tests begin.

| ID | Risk | L | C | Priority | Initial response |
|---|---|---:|---:|---:|---|
| R-001 | Cam and follower errors prevent one-minute indication. | 3 | 5 | 15 | CNC POM cam tolerance is 0.05 mm; run P2 pilot-fit and runout coupons before release, then report results without claiming the target prematurely. |
| R-002 | Backlash causes different answers depending on setting direction. | 3 | 4 | 12 | Spring-preload rack flanks and followers; procedure records bidirectional hysteresis. |
| R-003 | Variable-latitude surface cams bind or lose follower contact. | 3 | 5 | 15 | Analyze surface slopes; use roller followers; prototype the surface module independently. |
| R-004 | One-minute accuracy cannot be read on the chosen dial. | 4 | 3 | 12 | Separate calculated accuracy from readable resolution; use large dials and five-minute markings. |
| R-005 | Frame flexibility overwhelms cam accuracy. | 2 | 4 | 8 | 20x40 perimeter/crossmembers and local 6 mm plates; measure deflection and shaft normality. |
| R-006 | Rack differential adds excessive play or friction. | 3 | 4 | 12 | Use quality-8 module-1 parts, dual linear rails, opposed flank springs, and module-first acceptance. |
| R-007 | Coaxial azimuth hands are difficult to fabricate and align. | 3 | 3 | 9 | Ground 8 mm inner shaft, 14/8.1 mm tube, replaceable bushings, wave-spring preload. |
| R-008 | Astronomical convention differs from published sunrise data. | 1 | 3 | 3 | Mitigated for P1: convention frozen and full year passes NREL SPA vs JPL DE421 validation; retain ideal-horizon warning. |
| R-009 | Atmospheric and terrain effects are mistaken for mechanism error. | 3 | 3 | 9 | State that the display represents a standardized ideal horizon. |
| R-010 | POM cams move after rough machining or clamping. | 3 | 4 | 12 | Stress-relieved stock, rough/stabilize 24 h, finish pilot/profile together, coupon approval before production. |
| R-013 | Incorrect bearing compensation or follower geometry corrupts the cam scale. | 2 | 5 | 10 | Source generates the inward normal offset for a 16 mm roller; automated scale, closure, pressure-angle, and mesh checks run on every verification. |
| R-014 | Vendor silently smooths or resamples the cam profile. | 2 | 5 | 10 | STEP/DXF are geometry masters, CSV is inspection reference, RFQ forbids smoothing and requires 16-station results. |
| R-015 | Bending or parallax at the large hands dominates reading error. | 3 | 3 | 9 | 5052 hands, 1.5-3 mm dial gap, guard clearance, and integrated optical/angle check. |
| R-016 | P1 test bypass leaves follower and preload behavior uncharacterized. | 4 | 4 | 16 | P2 coupon gate and separate cam/time/azimuth module tests are mandatory before integration. |
| R-017 | Remote date-control belt phase error or compliance shifts both annual cam readings. | 3 | 4 | 12 | Use matched 30-tooth HTD-5M pulleys, mark the common zero tooth, set phase with the date coupon, tension at the specified idler, and record bidirectional date-index error before module acceptance. |
| R-011 | Annual automatic drive requires more torque than a clock movement supplies. | 4 | 3 | 12 | Keep early date input manual; characterize torque before choosing a drive. |
| R-012 | Uncontrolled scope shifts the project toward a wristwatch too early. | 3 | 5 | 15 | Treat the 36 by 24 inch demonstrator as the current product and wrist scale as a separate future project. |

## First risk-reduction experiments

1. Machine and inspect the three P2 calibration coupons before releasing production parts.
2. Assemble the fixed-latitude daylight cam module and measure follower repeatability and phase.
3. Assemble the fixed-latitude azimuth cam module and measure follower repeatability and phase.
4. Characterize the remote date-control belt phase and bidirectional error.
5. Measure frame and shaft deflection under the intended preload.
6. Test each reversible output transmission and quantify lost motion before integration.

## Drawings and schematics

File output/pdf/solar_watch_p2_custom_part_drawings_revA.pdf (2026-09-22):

P2-A00 DRAWING INDEX | SHEET 1 OF 32 | REV A | mm
P2-A01 | GENERAL ARRANGEMENT
P2-A02 | EXPLODED MODULE STACK
P2-A03 | KINEMATIC / INTERFACE DIAGRAM
P2-101 | DAYLIGHT-DURATION CAM
P2-102 | SUNRISE-AZIMUTH CAM
P2-103 | CAM HUB
P2-104 | CAM MODULE PLATE
P2-105 | DAYLIGHT SPAN LEVER
P2-106 | AZIMUTH SPAN LEVER
P2-107 | TIME CARRIER PLATE
P2-108 | TIME MODULE PLATE
P2-109 | AZIMUTH MODULE PLATE
P2-110 | SUNRISE TIME SHAFT
P2-111 | SUNSET OUTPUT SHAFT
P2-112 | AZIMUTH INNER SHAFT
P2-113 | AZIMUTH OUTER TUBE
P2-114 | FRONT LAYOUT
P2-115 | FRONT GUARD
P2-116 | TIME DIAL
P2-117 | AZIMUTH DIAL
P2-118 | TIME HAND
P2-119 | AZIMUTH HAND
P2-120 | CAM RUNOUT COUPON
P2-121 | HUB PILOT FIT COUPON
P2-122 | LEVER SPAN GAUGE
P2-123 | COMMON CAM / DATE SHAFT
P2-124 | CAM FOLLOWER CARRIAGE
P2-125 | RACK CLAMP
P2-126 | CARRIER OUTPUT-RACK BRACKET
P2-127 | AZIMUTH GEAR BUSHING
P2-128 | DATE CONTROL SHAFT

Every numbered custom part has STEP/DXF geometry; STL is preview-only. PDF notes and the ICD control tolerances and inspection.

P2-A01 GENERAL ARRANGEMENT | SHEET 2 OF 32 | REV A | mm

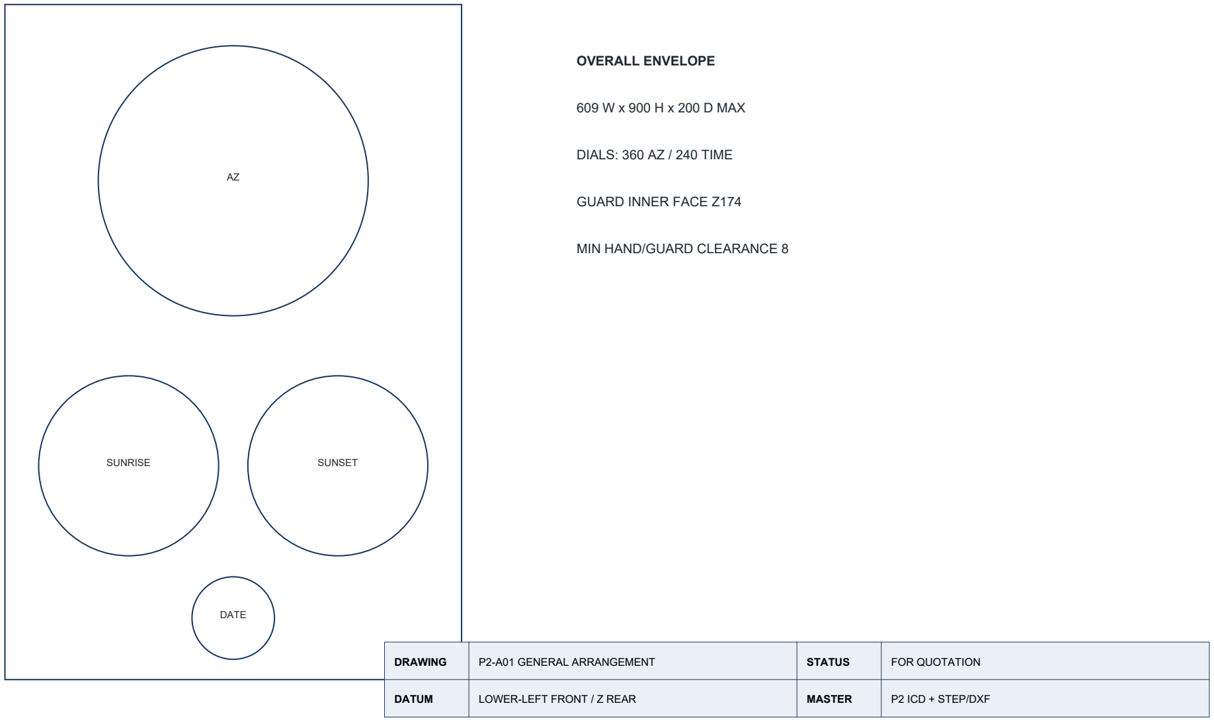
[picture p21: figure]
SUNRISE; SUNSET; DATE; OVERALL ENVELOPE; 609 W x 900 H x 200 D MAX; DIALS: 360 AZ / 240 TIME; GUARD INNER FACE Z174; MIN HAND/GUARD CLEARANCE 8; DRAWING; P2-A01 GENERAL ARRANGEMENT; STATUS; FOR QUOTATION; DATUM; LOWER-LEFT FRONT / Z REAR; MASTER; P2 ICD + STEP/DXF

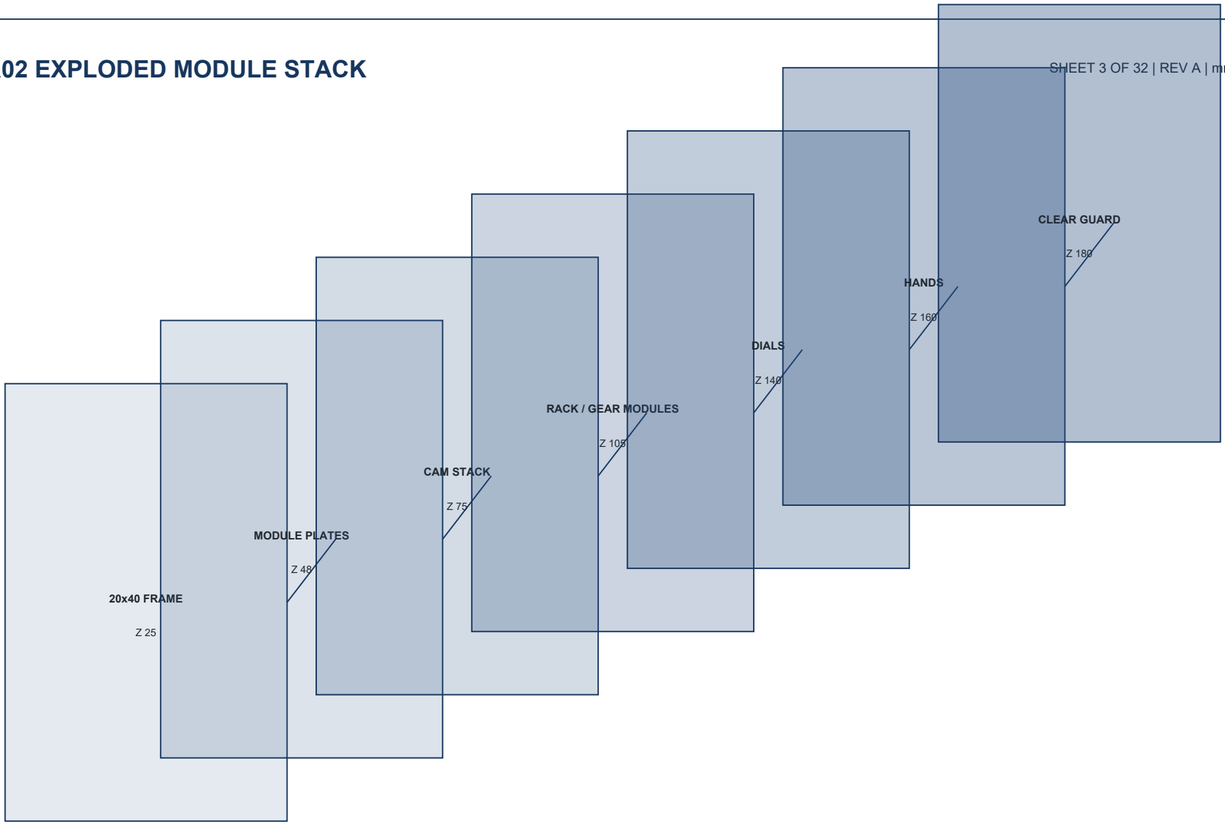
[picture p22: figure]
20x40 FRAME; MODULE PLATES; CAM STACK; RACK / GEAR MODULES; DIALS; HANDS; CLEAR GUARD

P2-A02 EXPLODED MODULE STACK | SHEET 3 OF 32 | REV A | mm

Assembly order: square frame -> datum plates -> shafts/cams -> racks/gears -> dials -> hands -> guard. Service removal is the reverse; calibrated modules remain installed.

DRAWING | P2-A02 EXPLODED MODULE STACK | STATUS | FOR QUOTATION
DATUM | LOWER-LEFT FRONT / Z REAR | MASTER | P2 ICD + STEP/DXF

P2-A03 KINEMATIC / INTERFACE DIAGRAM | SHEET 4 OF 32 | REV A | mm

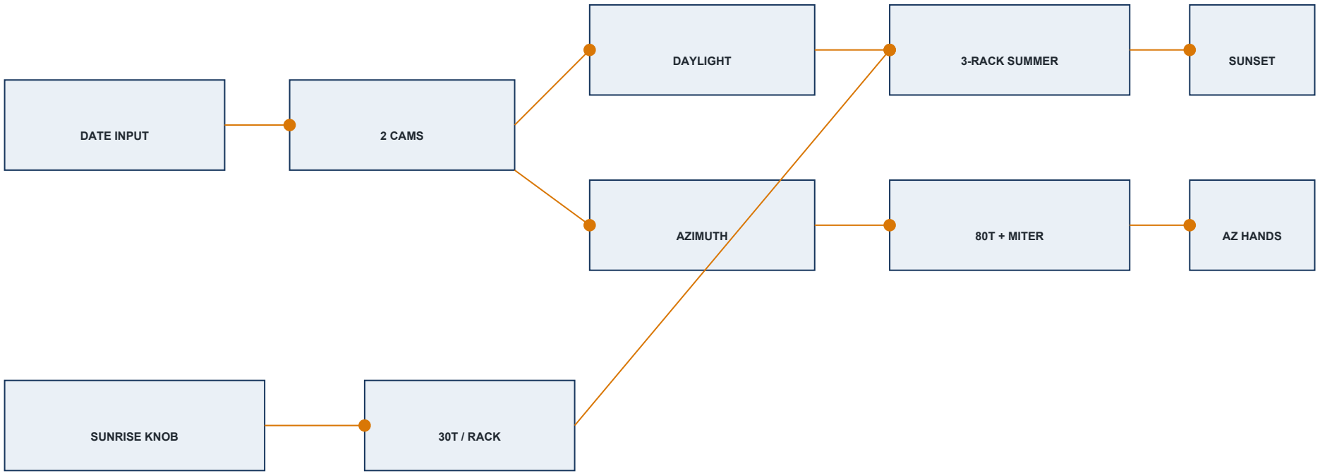
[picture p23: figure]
DATE INPUT; 2 CAMS; DAYLIGHT; AZIMUTH; 3-RACK SUMMER; 80T + MITER; SUNSET; AZ HANDS; SUNRISE KNOB; 30T / RACK

TIME: x_carrier=(x_sunrise+x_daylight)/2; 7.5 mm output radius restores full sum.

AZIMUTH: 40 mm pitch radius gives 1 deg output per 0.6981317 mm; 1:1 miter reverses sunset.

All three modules expose independent zero/span/phase adjustments after guard removal.

DRAWING | P2-A03 KINEMATIC / INTERFACE DIAGRAM | STATUS | FOR QUOTATION
DATUM | LOWER-LEFT FRONT / Z REAR | MASTER | P2 ICD + STEP/DXF

P2-101 DAYLIGHT-DURATION CAM | SHEET 5 OF 32 | REV A | mm

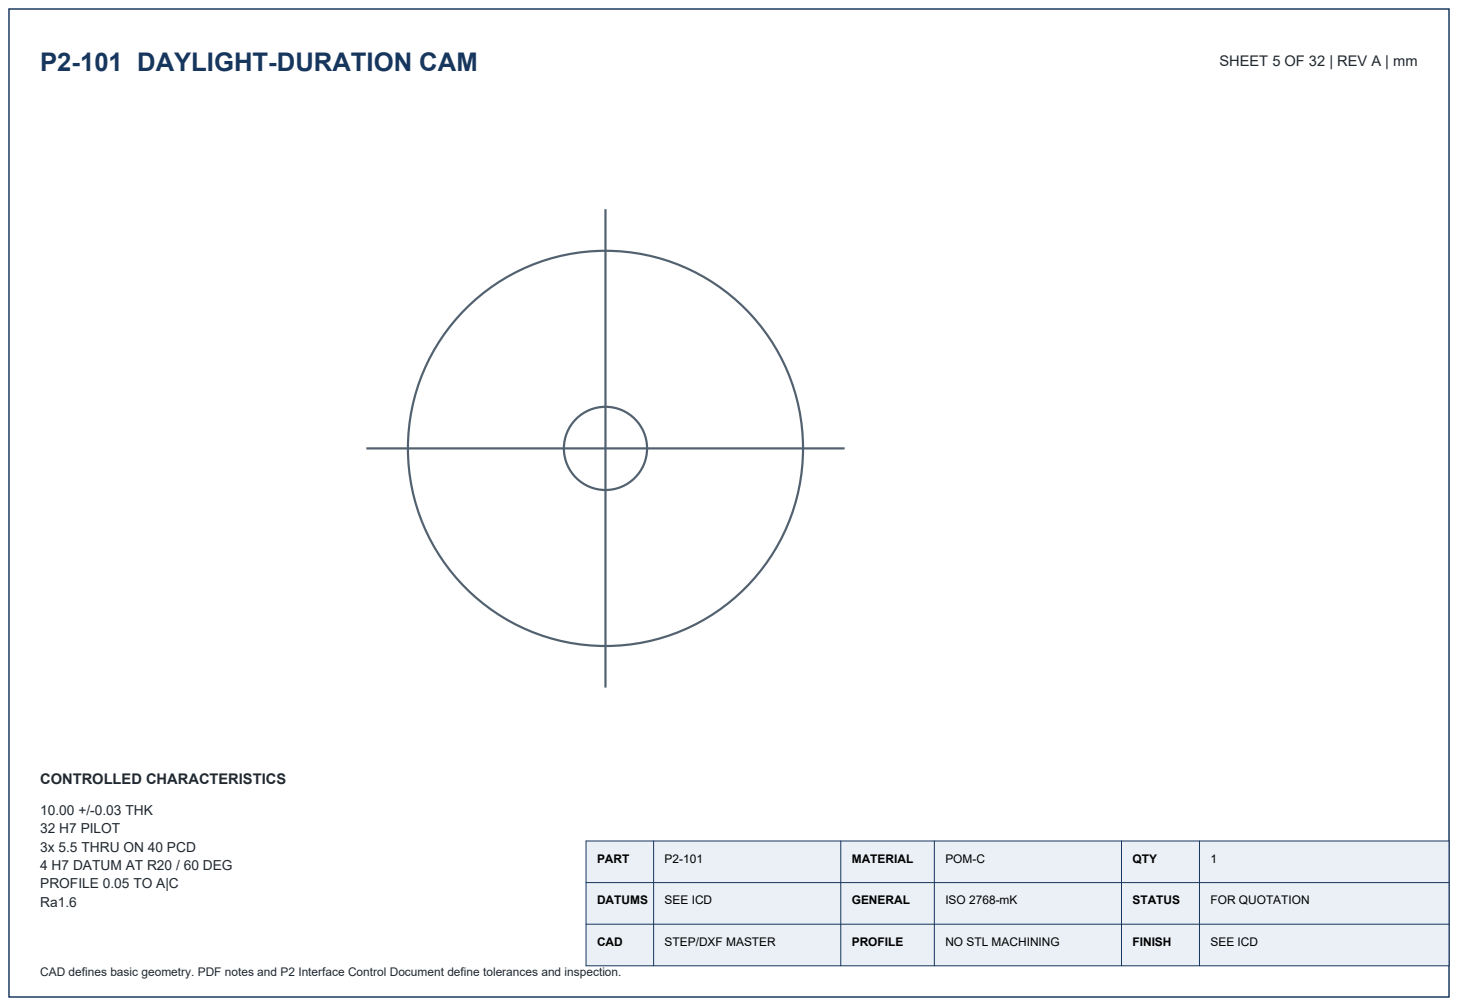
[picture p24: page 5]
CONTROLLED CHARACTERISTICS

10.00 +/-0.03 THK
32 H7 PILOT
3x 5.5 THRU ON 40 PCD
4 H7 DATUM AT R20 / 60 DEG
PROFILE 0.05 TO A|C

PART | P2-101 | MATERIAL | POM-C | QTY | 1

DATUMS | SEE ICD | GENERAL | ISO 2768-mK | STATUS | FOR QUOTATION

CAD | STEP/DXF MASTER | PROFILE | NO STL MACHINING | FINISH | SEE ICD

CAD defines basic geometry. PDF notes and P2 Interface Control Document define tolerances and inspection.

P2-102 SUNRISE-AZIMUTH CAM | SHEET 6 OF 32 | REV A | mm

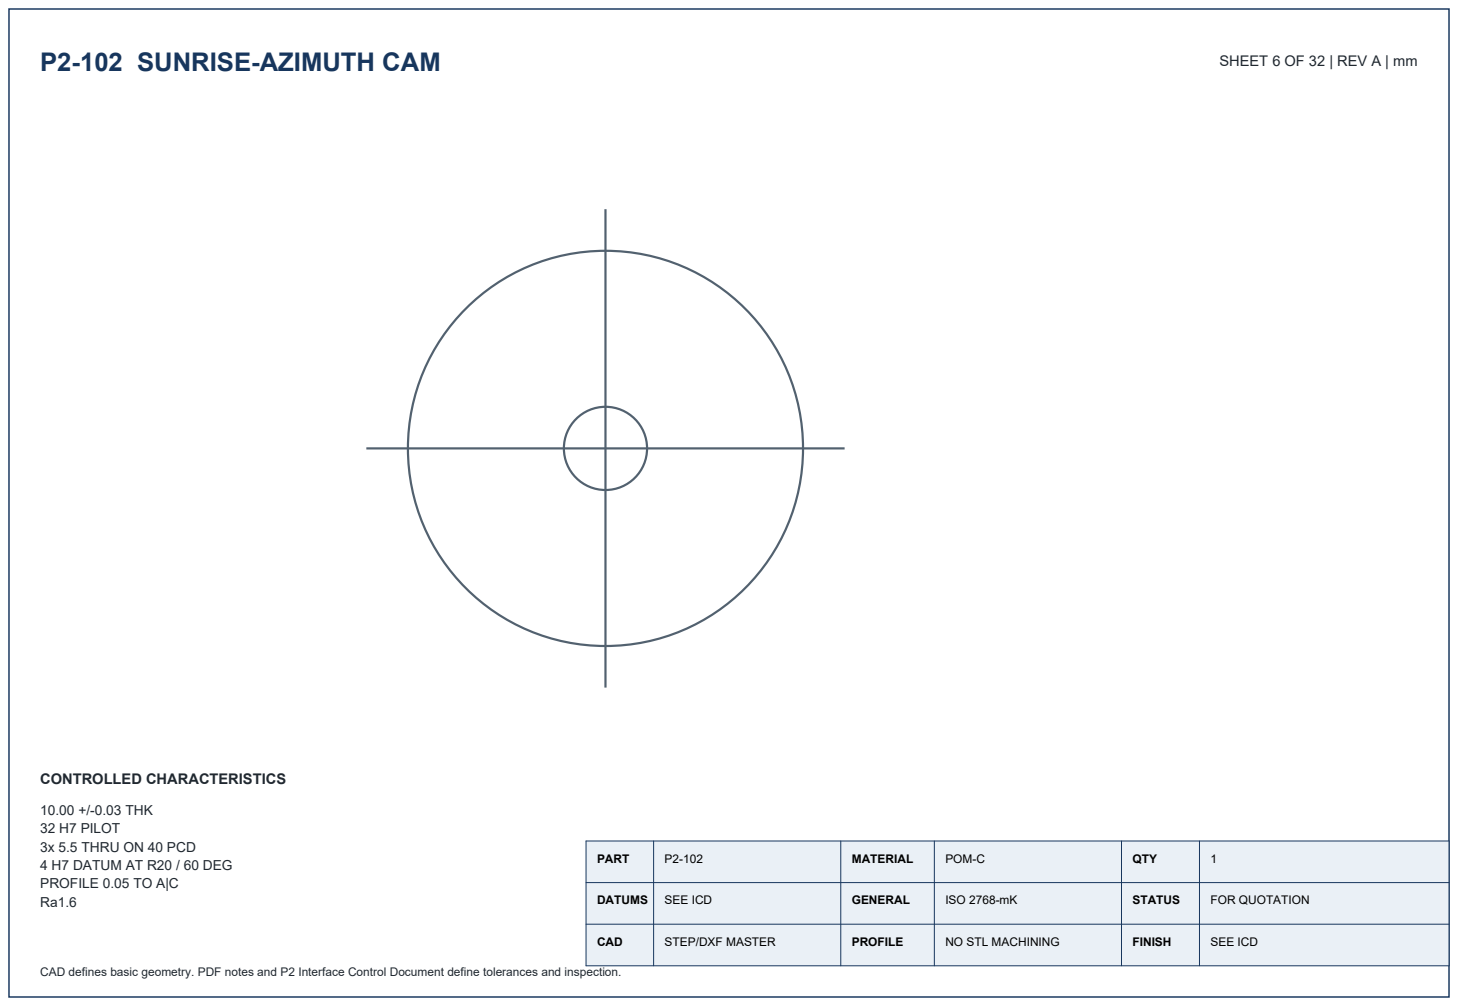
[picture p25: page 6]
CONTROLLED CHARACTERISTICS

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

PART | P2-102 | MATERIAL | POM-C | QTY | 1

DATUMS | SEE ICD | GENERAL | ISO 2768-mK | STATUS | FOR QUOTATION

CAD | STEP/DXF MASTER | PROFILE | NO STL MACHINING | FINISH | SEE ICD

P2-103 CAM HUB | SHEET 7 OF 32 | REV A | mm

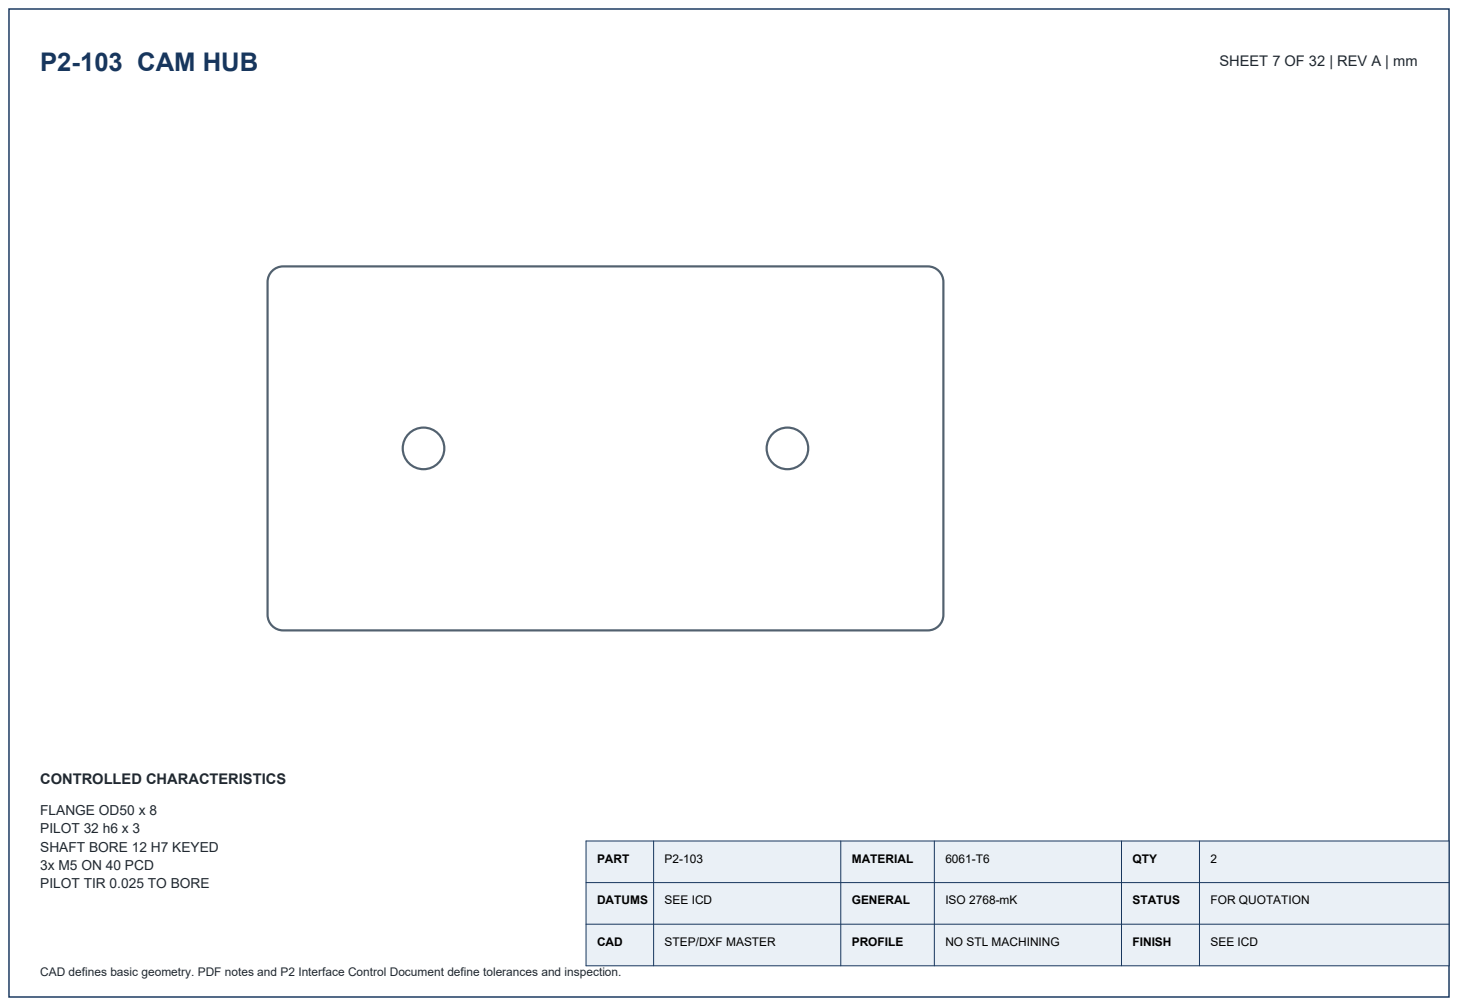
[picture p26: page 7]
CONTROLLED CHARACTERISTICS

FLANGE OD50 x 8
PILOT 32 h6 x 3
SHAFT BORE 12 H7 KEYED
3x M5 ON 40 PCD
PILOT TIR 0.025 TO BORE

PART | P2-103 | MATERIAL | 6061-T6 | QTY | 2

DATUMS | SEE ICD | GENERAL | ISO 2768-mK | STATUS | FOR QUOTATION

CAD | STEP/DXF MASTER | PROFILE | NO STL MACHINING | FINISH | SEE ICD

P2-104 CAM MODULE PLATE | SHEET 8 OF 32 | REV A | mm

DATE BORE 28 AT (-80,-75)
LEVER PIVOT 8 H7 AT (80,0)
4x FRAME 6.6 AT (+/-165,+/-155)
GUIDE HOLES PER DXF

PART | P2-104 | MATERIAL | 6061-T6 | QTY | 1

DATUMS | SEE ICD | GENERAL | ISO 2768-mK | STATUS | FOR QUOTATION

CAD | STEP/DXF MASTER | PROFILE | NO STL MACHINING | FINISH | SEE ICD

P2-105 DAYLIGHT SPAN LEVER | SHEET 9 OF 32 | REV A | mm

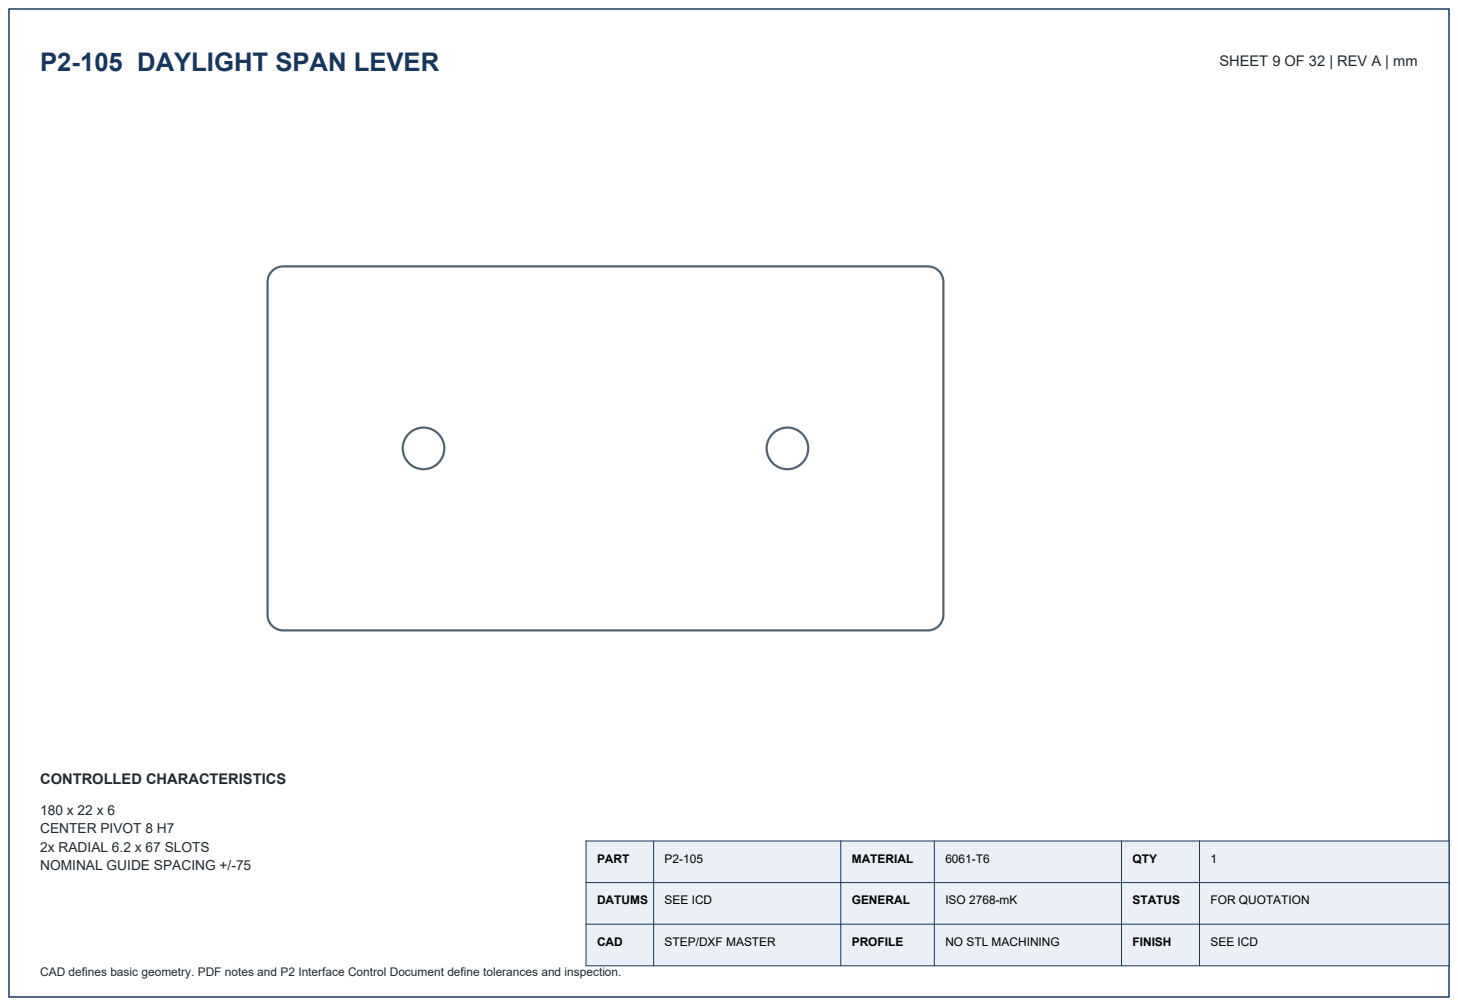
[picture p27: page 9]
CONTROLLED CHARACTERISTICS; 180 x 22 x 6 CENTER PIVOT 8 H7 2x RADIAL 6.2 x 67 SLOTS; NOMINAL GUIDE SPACING +/-75; PART; MATERIAL; QTY

DATUMS | SEE ICD | GENERAL | ISO 2768-mK | STATUS | FOR QUOTATION

CAD | STEP/DXF MASTER | PROFILE | NO STL MACHINING | FINISH | SEE ICD

P2-106 AZIMUTH SPAN LEVER | SHEET 10 OF 32 | REV A | mm
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

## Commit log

2026-09-21 Deliver validated P0 model and P1 cam package
    Validate NREL SPA against JPL DE421 for all 365 days at 42.1 N. Generate roller-compensated daylight and sunrise-azimuth cams, printable calibration coupons, plots, tables, tests, BOM, and print/cali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
    [608_bearing_fit_21p9_to_22p3_revA.stl, constant_radius_runout_revA.stl, daylight_42p1N_revA.stl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]
2026-09-22 feat: deliver CNC-ready P2 solar watch package
    [P2-101_daylight_42p1N_p2_revA.dxf, P2-101_daylight_42p1N_p2_revA.step, P2-101_daylight_42p1N_p2_revA.stl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]
